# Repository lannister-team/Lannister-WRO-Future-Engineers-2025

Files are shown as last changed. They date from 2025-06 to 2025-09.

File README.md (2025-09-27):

<h1 align="center"><strong>Lannister Team</strong></h1>

<p align="center"><strong>WRO 2025 Local Final: Future Engineers</strong></p>

<p align="center">
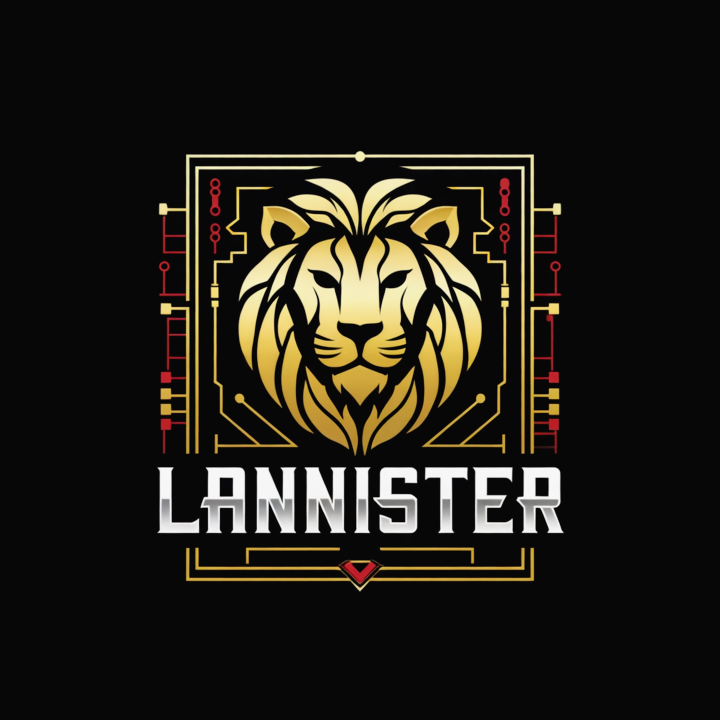
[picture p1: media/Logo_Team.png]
Lannister Team Logo
  
</p>

<p align="center">
  This is the official repository of <strong>Team Lannister</strong> for the international final of the <strong>WRO2025</strong> season.
</p>

## Table of Contents

- [Engineering Materials Repository](#engineering-materials-repository)
  - [Folder Structure](#-folder-structure)
    - [t-photos](#t-photos)
    - [v-photos](#v-photos)
    - [video](#video)
    - [schemes](#schemes)
    - [src](#src)
    - [models](#models)
    - [media](#media)
  - [Car Components](#-car-components)
    - [Introduction](#introduction)
    - [Mobility Management Components](#mobility-management-components)
    - [Motor Integration and Drive System](#-motor-integration-and-drive-system)
      - [Drive System Overview](#--drive-system-overview)
    - [Ackermann Steering System](#-ackermann-steering-system)
      - [How it works](#--how-it-works)
    - [System Elements Overview](#-system-elements-overview)
      - [Microcontrollers and Computing Units](#-microcontrollers-and-computing-units)
        - [Arduino Uno](#arduino-uno)
        - [Raspberry Pi 5 (Model B)](#raspberry-pi-5-model-b)
      - [Vision System](#-vision-system)
      - [Motors and Actuation](#-motors-and-actuation)
      - [Motor Driver](#-motor-driver)
      - [Distance and Motion Sensing](#-distance-and-motion-sensing)
      - [Power Supply](#-power-supply)
    - [Coding Environments](#-coding-environments)
      - [Arduino IDE (C++)](#-arduino-ide-c)
      - [Python](#-python)

# Engineering Materials Repository

This repository contains all materials related to our engineering vehicle project for the competition. The content is organized into several folders as described below.

---

##  Folder Structure

### `t-photos`
- Contains **2 team photos**:
  - An **official team photo**.
  - A **funny photo** with all team members.
  ## 👥 Team Photos

Here are some photos of our team.

| Team Photo | Funny Team Photo |
|---|---|
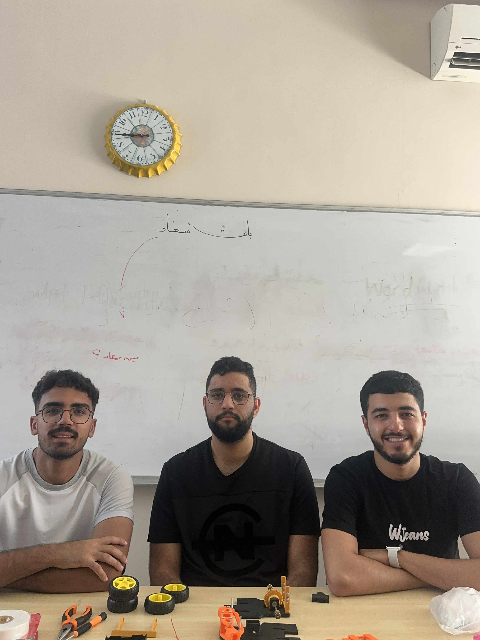
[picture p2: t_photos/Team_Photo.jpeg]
Team Photo
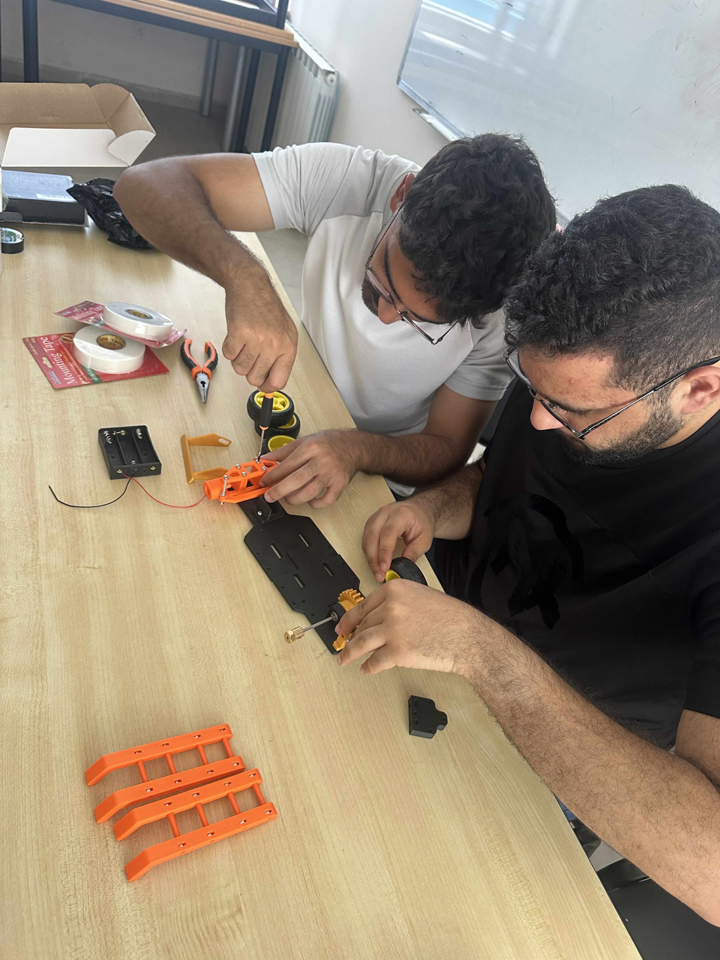
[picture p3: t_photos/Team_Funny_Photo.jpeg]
Funny Team Photo
|  |  |

### `v-photos`
- Contains **6 photos of the vehicle**:
  - Captured from **every side**, as well as from the **top and bottom**.
  ## 📸 Vehicle Photos

Here you can see a selection of the vehicle photos from different angles.  
All images are stored inside the `v_photos/` folder.

| Top view | Front view | Back view |
|---|---|---|
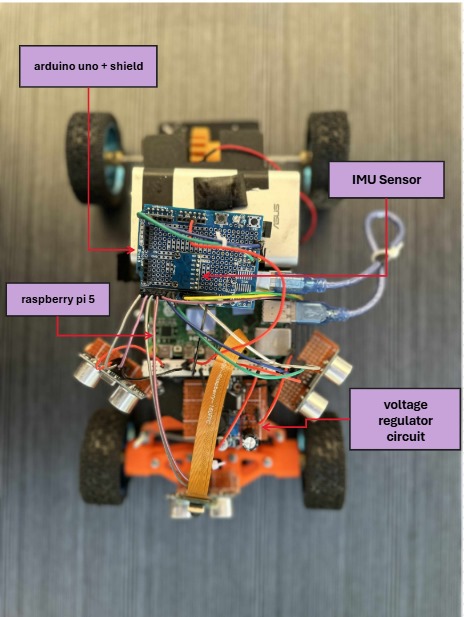
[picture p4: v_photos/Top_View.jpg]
Top view
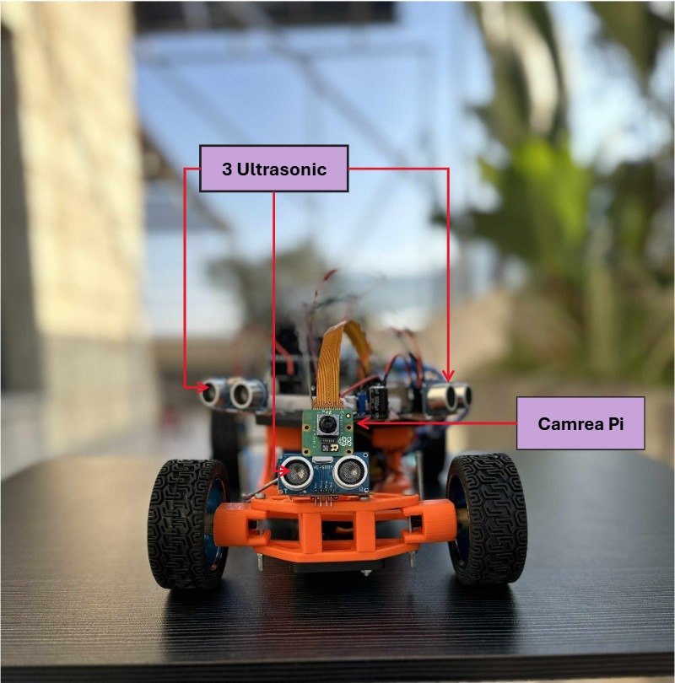
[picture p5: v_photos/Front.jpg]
Front view
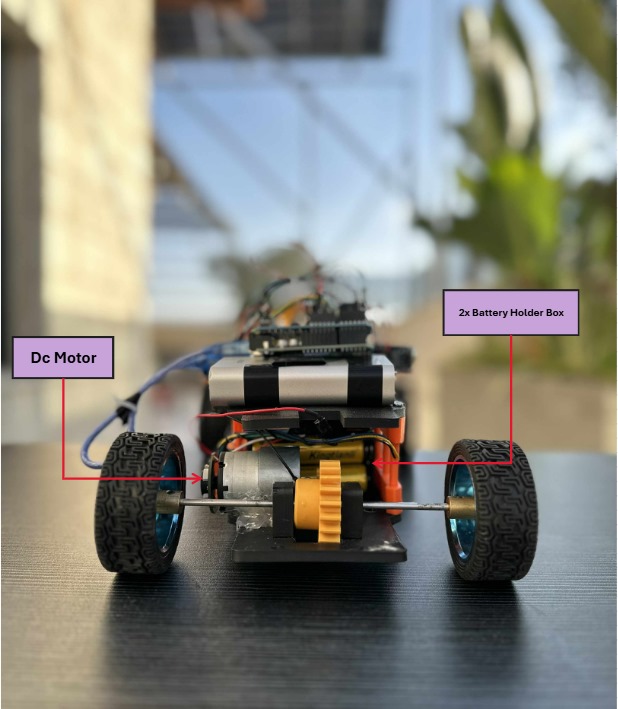
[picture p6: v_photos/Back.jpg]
Back view
|  |  |  |

| Bottom view | Left view | Right view |
|---|---|---|
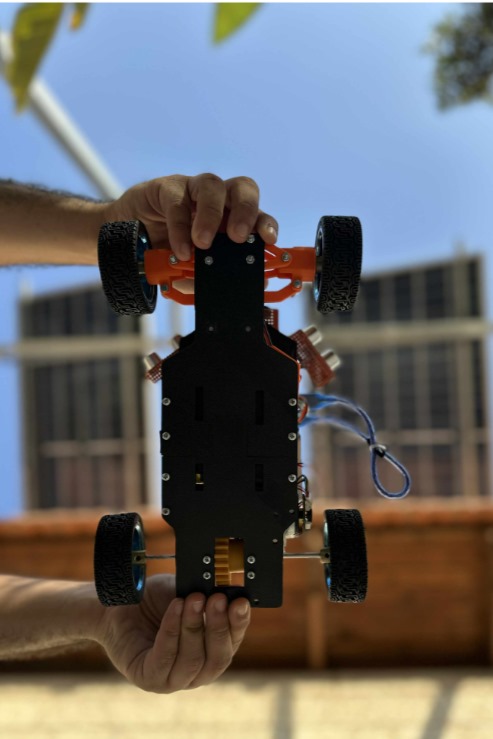
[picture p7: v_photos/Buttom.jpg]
Bottom view
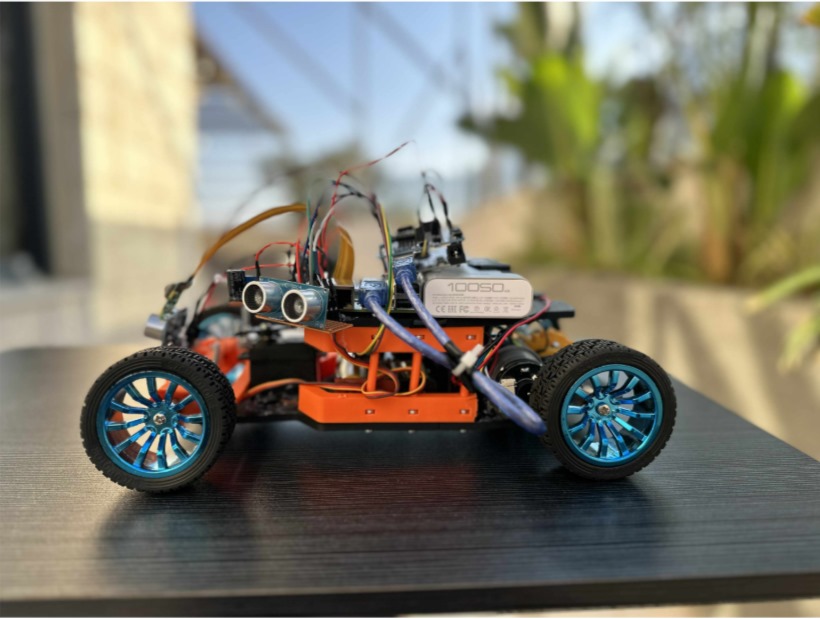
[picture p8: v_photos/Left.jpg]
Left view
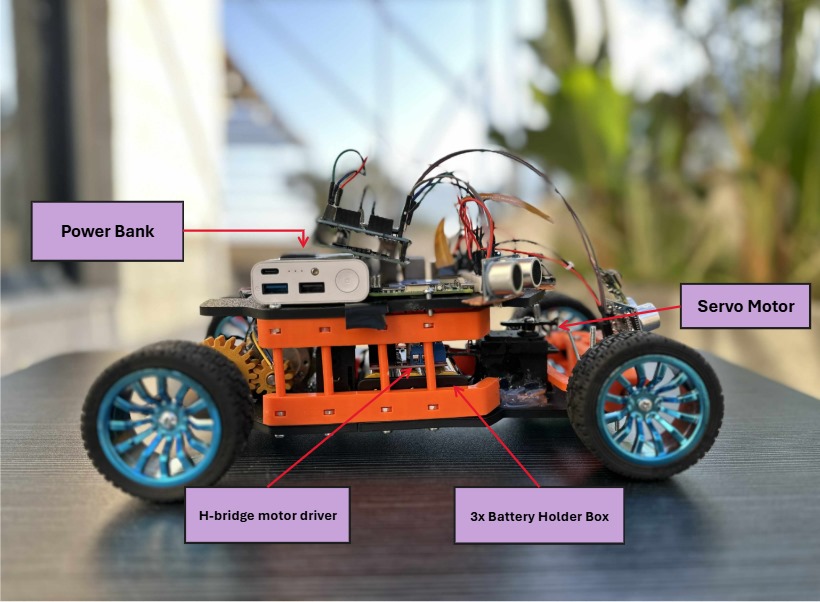
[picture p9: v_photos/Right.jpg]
Right view
|  |  |  |

### `video`
- Contains a `video.md` file with a **link to a demonstration video** showing the vehicle in action.

### `schemes`
- Contains **schematic diagrams** in **JPEG**, **PNG**, or **PDF** format.
- Illustrates all **electromechanical components** used in the vehicle:
  - Electronic components
  - Motors
  - Wiring and connections between them

### `src`
- Contains the **source code** for the control software.
- Includes all components programmed to participate in the competition.

### `models`

- Contains **illustrative diagrams and conceptual models** related to the mechanical design of the robot, including:
  - *Ackermann Steering System in Our WRO 2025 Car*
  - *Differential Gear System in Our WRO 2025 Car*
- These models are used for documentation and explanation purposes only, and do not include 3D-printable or CNC-ready files.
- This folder helps visualize how steering and torque distribution are mechanically implemented in the vehicle.

### `media`
- Contains **images and diagrams** used throughout the documentation, including:
  - Photos of hardware components (motors, sensors, controllers, etc.)
  - System wiring diagrams or mechanical schematics
  - Illustrations for the README and other documentation
- May also include other helpful files such as:
  - Datasets
  - Connection instructions to SBC/SBM
  - Hardware specifications and communication protocols

---

##  Car Components

This structure ensures clear organization and ease of navigation for anyone working on, reviewing, or evaluating the engineering project.

Introduction
Hello, Team Lannister here, let's go a deeper into how this seasons robot is made up !!

### Mobility Management Components

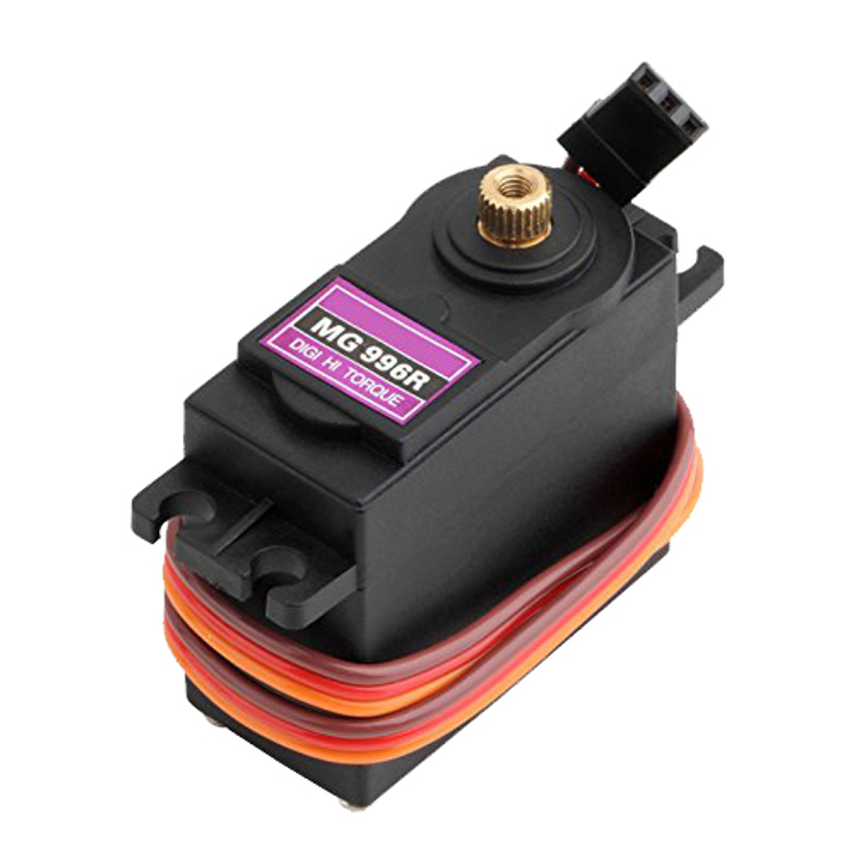
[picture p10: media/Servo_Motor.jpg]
MG996R Servo
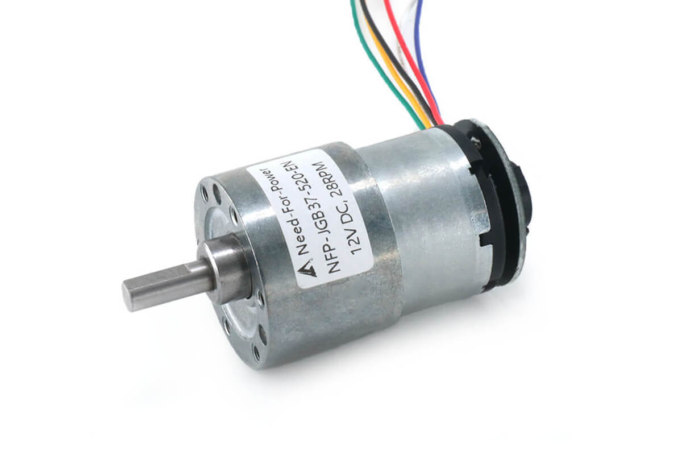
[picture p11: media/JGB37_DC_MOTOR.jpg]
JGB37-520 Encoder Gearmotor
|  |  |
|:---:|:---:|
| **MG996R Servo Motor** <br><br>• Weight: ~55g  <br>• Dimensions: 40.7 × 19.7 × 42.9 mm  <br>• Stall torque: 9.4 kgf·cm at 4.8V <br>• Stall torque: 11 kgf·cm at 6.0V <br>• Speed: 0.20s/60° at 4.8V (no load) <br>• Speed: 0.16s/60° at 6.0V (no load) <br>• Rotational range: 180° <br>• Pulse width: 500–2500 µs | **JGB37-520 Encoder Gearmotor (12V, 530 RPM, 18.8:1)** <br><br>• Rated voltage: 12V <br>• Speed: up to 530 RPM (no load) <br>• Gear ratio: 18.8:1 <br>• Shaft diameter: 6 mm <br>• Motor diameter: 37 mm <br>• Encoder resolution: 11 pulses per revolution <br>• No load current: ~120mA <br>• Stall current: ~2.8A <br>• Stall torque: ~3.2 kgf·cm |

###  Motor Integration and Drive System

To ensure proper implementation of the DC 12V encoder gear motor and the servo motor, both a motor driver and a mechanical differential were selected as essential components of the drive system.

The encoder gear motor is responsible for powering the mechanical differential, which then distributes motion evenly to the rear wheels. This configuration was chosen due to the torque multiplication offered by the differential — a key factor for achieving precise maneuverability within constrained environments, such as a competition playing field.

The integrated gear reduction system in the motor provides several advantages:

- Simplified mechanical design  
- Enhanced power and torque output  
- High durability due to the sealed and enclosed housing  

This combination of components enables smooth, responsive, and reliable mobility suitable for both fine control and sustained movement under varying load conditions.

####  Drive System Overview

<p align="center">
  Mechanical Differential
</p>

---

###  Ackermann Steering System

To achieve realistic turning behavior and reduce tire slip during sharp turns, the robot implements an **Ackermann steering mechanism**. This system is commonly used in cars and robotics for accurate cornering.

####  How it works:

When a vehicle turns, the inner front wheel must rotate at a **sharper angle** than the outer wheel. Ackermann steering geometry ensures this by linking the steering arms to pivot at a calculated angle, allowing the two front wheels to point towards the center of a turning circle.

This offers the following benefits:

- Reduced tire wear during turns  
- Improved energy efficiency  
- More accurate and realistic path-following behavior  
- Ideal for tight indoor environments like robotic competitions

<p align="center">
  Ackermann Steering Diagram
</p>

---

###  System Elements Overview

This section outlines the main hardware components integrated into the robot, including control units, sensors, power elements, and motor drivers.

---

####  Microcontrollers and Computing Units

### Arduino Uno

The Arduino Uno serves as the main microcontroller responsible for low-level control tasks such as motor actuation and sensor data acquisition. It interfaces directly with the motor driver, sensors, and power supply through individual wiring and connections without the use of a custom shield.

Connections are managed via standard Arduino input/output pins, with careful wiring to ensure stable power distribution and reliable communication with all peripheral components.

<p align="center">
  Arduino Uno
</p>

To simplify wiring and improve reliability, we also used an **Arduino Shield**.  
The shield allowed us to:
- Reduce the complexity of manual wiring.  
- Ensure more stable connections between the Arduino and external modules.  
- Provide an easier way to connect sensors, motors, and the power supply without soldering.  

<p align="center">
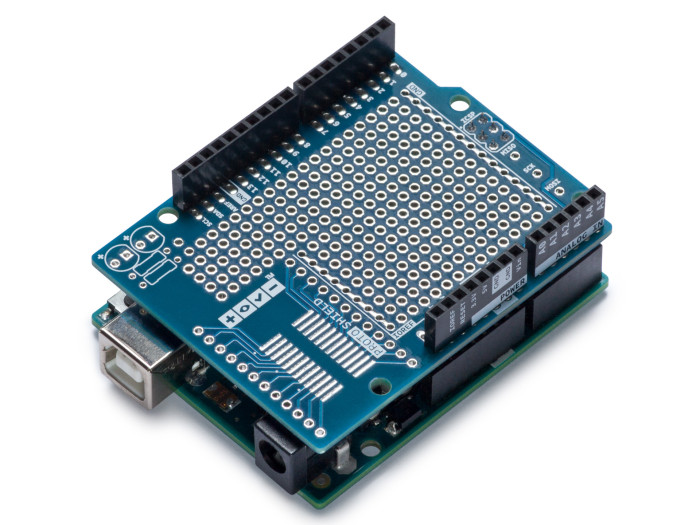
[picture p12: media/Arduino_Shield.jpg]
Arduino Shield
  
</p>

### Raspberry Pi 5 (Model B)

The Raspberry Pi 5 serves as the high-level processing unit, handling tasks such as path planning, camera data processing, and advanced control logic. Model B features a quad-core ARM Cortex-A76 processor running at 2.4GHz, up to 8GB RAM, dual 4K display output, USB 3.0 support, Gigabit Ethernet, built-in Wi-Fi and Bluetooth 5.0.

<p align="center">
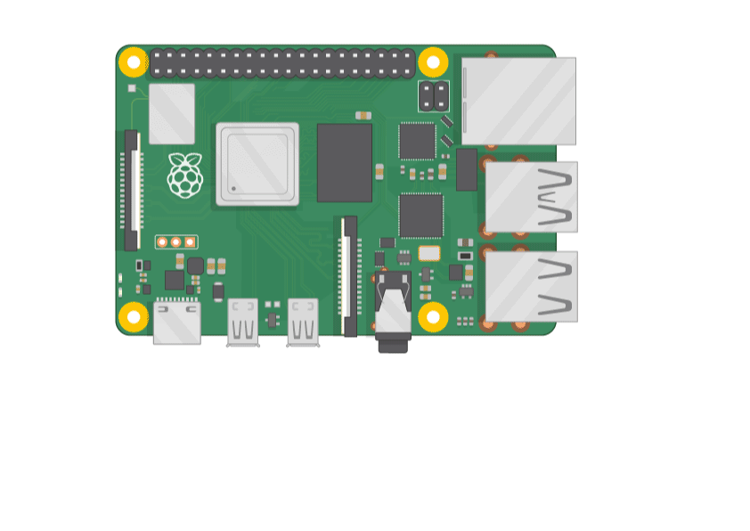
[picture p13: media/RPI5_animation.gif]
Raspberry Pi 5
  
</p>

---

####  Vision System

- **Raspberry Pi Camera Module**  
  The robot is equipped with the official Raspberry Pi Camera Module, providing real-time video input for image-based navigation or line-following tasks. The camera is directly connected to the Pi via the CSI interface for low-latency image capture.

<p align="center">
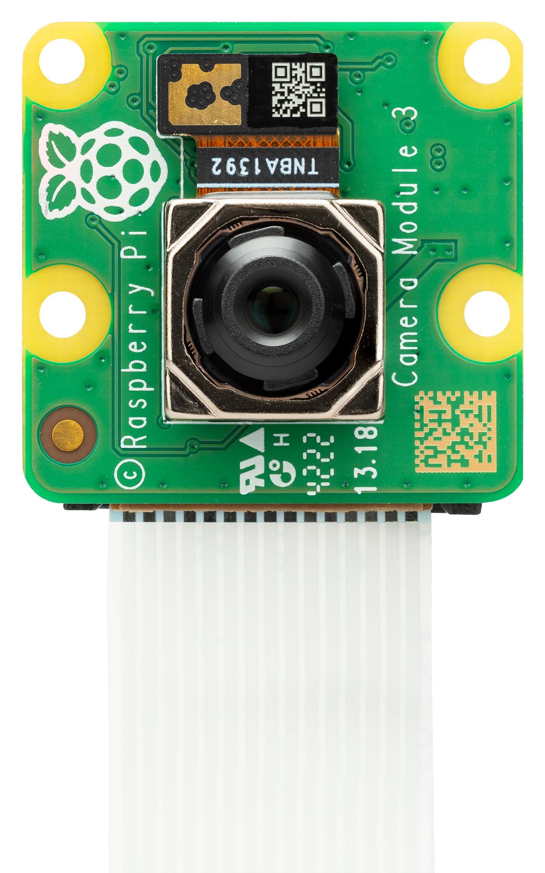
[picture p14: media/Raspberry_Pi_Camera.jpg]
Raspberry Pi Camera Module
  
</p>

---

####  Motors and Actuation

- **Motors Configuration**  
  The robot includes:
  - **1 DC Encoder Gearmotor** for rear-wheel drive (forward and backward motion).
  - **1 SG90 Servomotor** for steering the front wheels (left/right movement).

  These motors work together to allow omnidirectional navigation on a flat surface. Specifications include:
  - Torque: ~35 g·cm
  - Speed range: 0.22 m/s (min) – 0.71 m/s (max)  
  *(Note: 0.22 m/s is the robot's minimum effective speed; the motor itself can operate slower.)*

---

####  Motor Driver

- **L298N Dual H-Bridge Motor Driver**  
  The L298N module is used to control the DC and servo motors. It consists of:
  - An L298 integrated motor driver IC
  - A 78M05 5V regulator
  
  Features:
  - Can control up to 2 DC motors (direction + speed), but two in out car
  - Compatible with TTL logic levels (from Arduino UNO)

<p align="center">
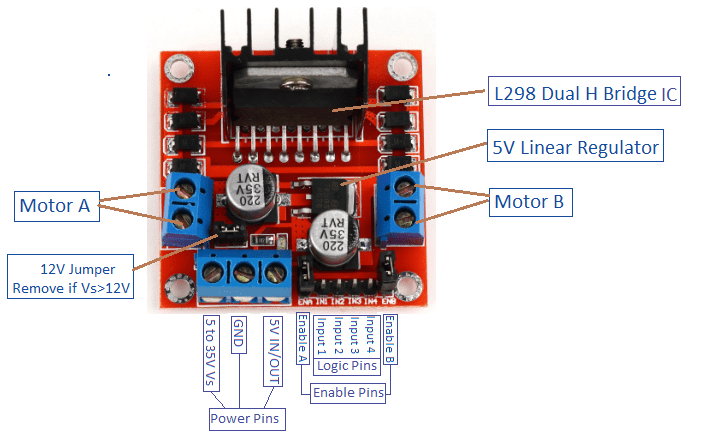
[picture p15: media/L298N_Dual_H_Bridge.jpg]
L298N Motor Driver
  
</p>

---

####  Distance and Motion Sensing

- **HC-SR04 Ultrasonic Sensors**  
  The robot uses **3 ultrasonic sensors** placed at the front, left, and right to detect obstacles and measure distances. Each sensor operates as follows:
  - Emits 8 ultrasonic pulses at 40kHz via the TRIG pin.
  - Detects reflected sound using the ECHO pin.
  - Measures time of flight to calculate distance (2–450 cm range).
  
  These sensors are not affected by sunlight or dark materials, but may struggle with acoustically soft surfaces (e.g., cloth or wool).

<p align="center">
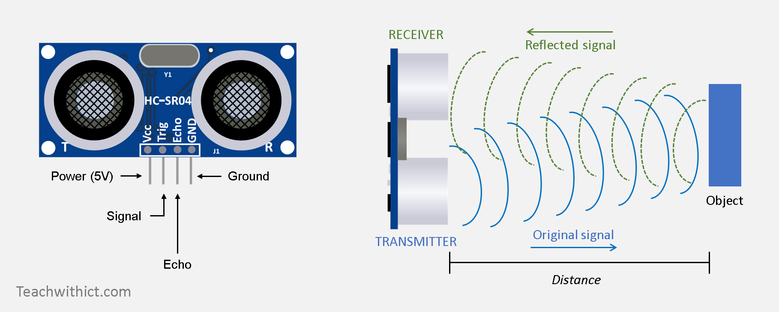
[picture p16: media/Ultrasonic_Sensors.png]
Ultrasonic Sensors
  
</p>

- **IMU Sensor (Inertial Measurement Unit)**  
  The robot includes an IMU sensor (e.g., MPU6050 or similar) that provides motion data through **gyroscope and accelerometer readings**. This allows:
  - Orientation tracking
  - Tilt detection
  - Smoother navigation control (especially in turns or uneven motion)

  The IMU is connected via I2C to the Arduino, which processes raw motion data or forwards it to the Raspberry Pi for sensor fusion and decision making.

<p align="center">
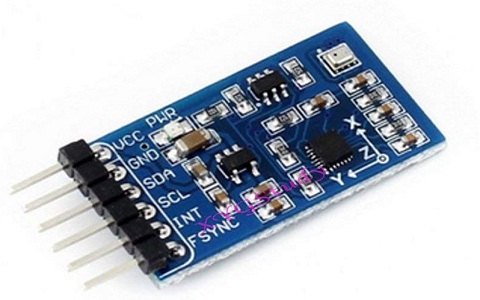
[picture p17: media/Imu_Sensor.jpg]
IMU Sensor
  
</p>

---

####  Power Supply

- **Power bank**
  The power bank will be our main source for keeping the Raspberry PI charged, which will also give the arduino its charge

- **3x - 3.7 Li-Po**  
  The robot is powered using a **3x - 3.7 Li-** Po-- 4.2 Max ~= 12.6v on max , to enable the motor to receive power through the L298N driver module.

###  Coding Environments

The robot's software is developed using two main programming environments: **Arduino IDE (C++)** and **Python**. Each environment is responsible for different layers of control, from low-level motor actuation to high-level vision processing.

---

####  Arduino IDE (C++)

The **Arduino Integrated Development Environment (IDE)** is a cross-platform application (available for Windows, macOS, and Linux) used to program Arduino-compatible boards. Written in Java, the IDE supports both C and C++ languages with simplified structure requirements.

Key features:
- Provides built-in libraries for common I/O operations (based on the Wiring framework).
- Requires only two user-defined functions: `setup()` for initialization and `loop()` for continuous execution.
- Uses the GNU toolchain to compile code, and **AVRDUDE** to upload the hex-encoded binary to the board.

**Role in the project:**
- The Arduino IDE is used to program the **Arduino Uno**, which directly controls:
  - Rear-wheel drive motion
  - Steering through the servo motor
- These actions are performed based on movement commands received from the Raspberry Pi Camera (e.g., left/right turns or forward/backward motion).

---

####  Python

**Python** is a high-level, interpreted programming language known for its readability and flexibility.

**Role in the project:**
- Python runs on the **Raspberry Pi 5** and is responsible for:
  - **Camera input handling**
  - **Color and object detection**
  - **Sending motion commands** to the Arduino Uno based on visual analysis

**Libraries**
- OpenCV library will be used to detecet colors (RED, GREEN).

##  Wiring Diagram

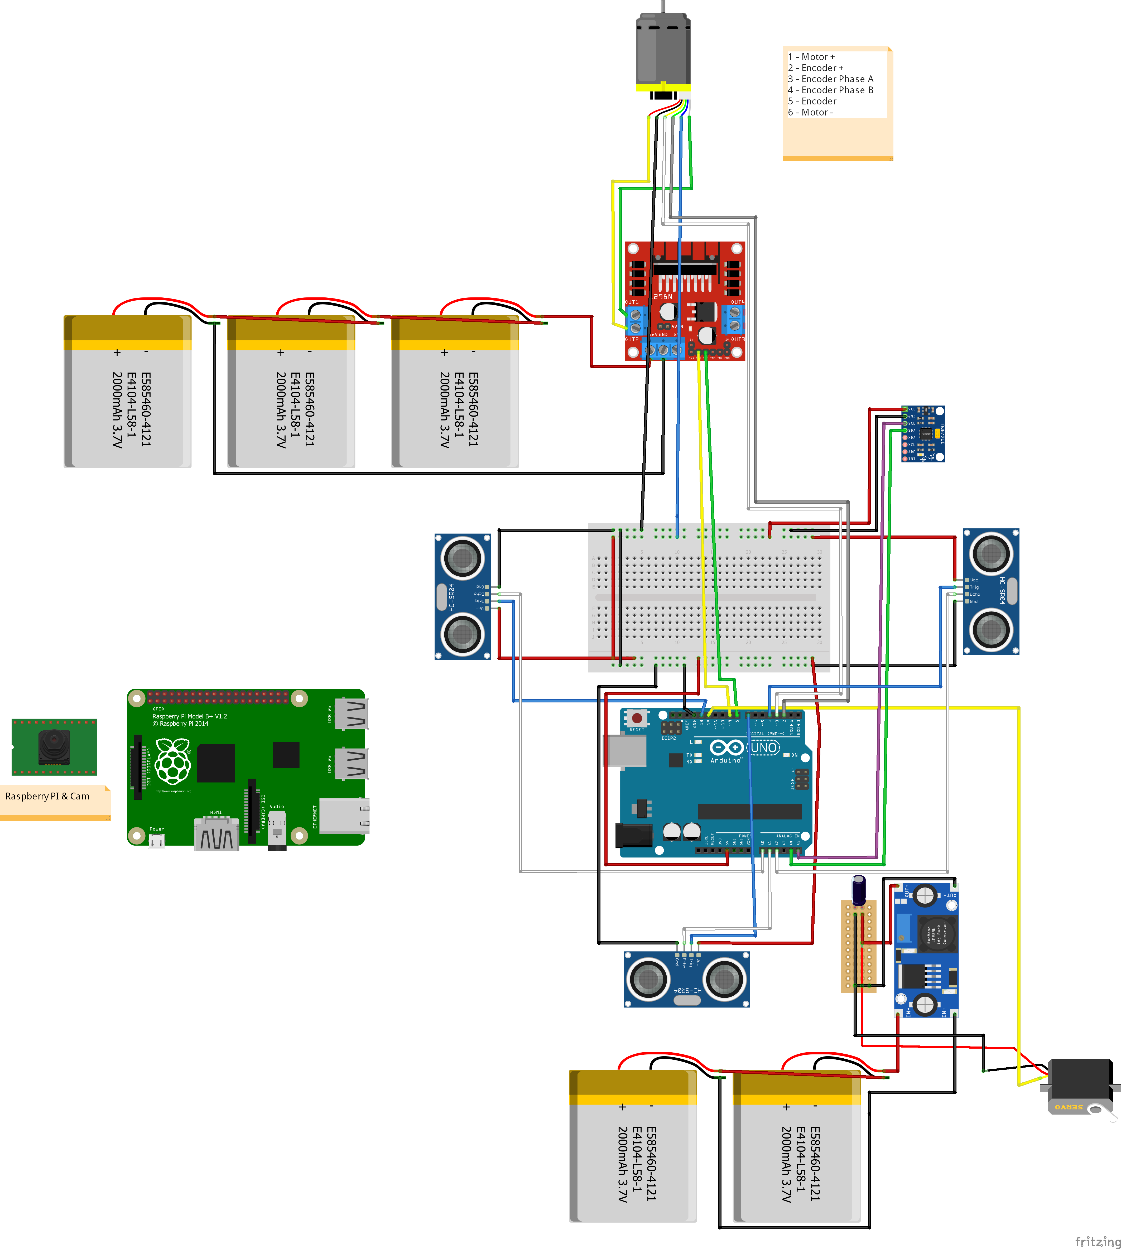
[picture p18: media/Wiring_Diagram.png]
Wiring Diagram


### Explanation

#### 1. Power Distribution
- **Motor Power (12V rail):**  
  Three Li-ion cells (3.7 V each) in series (~11.1 V) power the **L298N H-Bridge**.  
- **Logic Power (5V rail):**  
  Another pack (2 × 3.7 V = ~7.4 V) regulated to **6V** powers the **Arduino Uno**, sensors, and servo.  
- **All grounds are common** across Arduino, motor driver, sensors, and Raspberry Pi.

#### 2. Motor & Driver (L298N H-Bridge)
- **DC Gear Motor with Encoder** connected to OUT1/OUT2 of L298N.  
- Encoder outputs → Arduino digital pins.  
- IN1/IN2 → Arduino (motor direction).  
- ENA → Arduino PWM (speed control).  
- Powered from 3-cell battery pack.

#### 3. Sensors
- **Ultrasonic Sensors (x3 HC-SR04):**  
  Each wired with VCC, GND, Trig, Echo → Arduino pins (front, left, right).  
- **MPU6050 IMU:**  
  I²C (SDA → A4, SCL → A5), VCC (5V), GND.  
- **Raspberry Pi Camera:**  
  Connected to Raspberry Pi 5 CSI port.

#### 4. Actuators
- **Steering Servo Motor:**  
  Powered from regulated 6V, control pin → Arduino PWM.  
- **Relay Module:**  
  Controlled by Arduino digital pin for auxiliary switching.

#### 5. Controllers
- **Arduino Uno:** Low-level control for motor, sensors, and actuators.  
- **Raspberry Pi 5:** Vision processing with Pi Camera → sends movement commands via USB serial.

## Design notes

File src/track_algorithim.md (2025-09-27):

# Track Algorithim
this section for explaining the algorithim used in the Arduino files to win the track
##  Navigation Algorithm

The car’s navigation system combines data from the **IMU**, **Ultrasonic Sensors**, and the **Camera** to make real-time driving decisions.  

---

### 1. Forward Motion (IMU Correction)
- The car drives forward by default.  
- The **IMU (MPU6050)** continuously monitors orientation (yaw/pitch).  
- If the car drifts left or right:  
  - The system calculates the deviation.  
  - The **steering servo motor** adjusts the wheel angle to realign the car.  

---

### 2. Camera-Based Obstacle Detection
- The **Raspberry Pi Camera** identifies the color of the obstacle ahead:  
  - **Red →** The car avoids the obstacle by turning **right**.  
  - **Green →** The car overtakes by moving to the **left**.  

---

### 3. Ultrasonic Safety Check
- Three **ultrasonic sensors** are used: **front, left, and right**.  
- When the camera detects an obstacle:  
  - The system checks the corresponding ultrasonic sensor:  
    - **Red →** Check the **right sensor**.  
    - **Green →** Check the **left sensor**.  
  - If the chosen side is clear (distance above threshold), the car proceeds with the maneuver.  
  - If blocked, the car will **stop** to prevent collision.  

---

### 4. Realignment After Maneuver
- After completing a turn (right or left):  
  - The **IMU feedback** is used again to stabilize the direction.  
  - The **servo motor** returns the wheels to the corrected forward position.  

---

###  Summary of Logic
1. Drive forward and keep straight using the **IMU**.  
2. If the camera detects an obstacle:  
   - **Red → Turn Right** (if right side is clear).  
   - **Green → Overtake Left** (if left side is clear).  
3. Use **ultrasonic sensors** to ensure the chosen side is free.  
4. If blocked, **stop**.  
5. After turning, use **IMU correction** to continue straight.  

---

This algorithm ensures:  
- **Stability** through IMU correction.  
- **Safety** with ultrasonic distance checks.  
- **Smart decision-making** using camera color detection.

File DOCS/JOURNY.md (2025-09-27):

a jounry that shows our development process , choices , failures , improvements

##  Development Journey

Our development process was not a straight path—it was a journey full of challenges, failures, learning, and improvements. Below is an overview of the key stages we went through:

---

###  Step 1: First Steps with 3D Printing
- At the beginning, we struggled to learn how to design and work with **3D-printed parts**.  
- We tried creating our own designs, but the results were not practical.  
- Fortunately, we found an existing design online that fit our needs.  
- We made **major improvements and modifications** to adapt it to our project.  
- After printing the chassis, the result was promising, but a problem appeared:  
  - The **DC motor was longer than the chassis base**, causing fitting issues.  
- After several trials and adjustments, we solved this issue successfully.  

---

###  Step 2: Motor Limitations and Upgrades
- The original **DC motor was too weak** and could not deliver enough power.  
- We replaced it with a **stronger and more efficient motor**.  
- This upgrade was not straightforward—we faced difficulties with mounting and alignment.  
- With persistence, we managed to fix and stabilize the new motor in place.  

---

###  Step 3: Servo Motor Challenges
- The first **servo motor** we used had **low torque**, which was not enough for proper steering.  
- We upgraded to a **high-torque servo motor**.  
- The new servo required **6V power**, but our system could not supply this directly.  
- To solve this:  
  - We combined **two 3.7V Li-ion batteries** in series to get **7.4V**.  
  - We used a **voltage regulator** to clean and stabilize the output at **6V**.  
- This solution powered the high-torque servo safely and reliably.  

---

###  Conclusion
Every stage of our journey was a cycle of **trial and error**.  
Each challenge pushed us to learn and improve:  
- From mastering 3D printing,  
- To upgrading motors,  
- To solving power delivery issues.  

These experiences shaped our project into a **stronger, more reliable system**.

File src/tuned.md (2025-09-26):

How we tuned our sensors
Tuning & Calibration (Ultrasonic • IMU • Servo)

This vehicle didn’t work “out of the box.” We spent a lot of time tuning three pieces that control stability and decisions: the **steering servo**, the **ultrasonic sensors**, and the **IMU**. Below is how we approached each one and what we learned.

---

### 1) Steering Servo — center, left, right

**Goal**
- Find the exact **center angle** for straight driving, and the **left/right angles** for safe, consistent turns without over-steer.

**What we did**
- Locked the car on a flat surface and **swept the servo** in small steps to see when wheels actually point straight.
- Set an initial **CENTER** angle, then measured turning radius to define **LEFT_MAX** and **RIGHT_MAX** that do not hit mechanical limits.
- Added a small **dead-band** so tiny IMU noise doesn’t cause jitter.
- Limited the **rate of change** (deg/s) so turns are smooth.

**Problems we hit**
- The horn alignment and gear **backlash** made “90° = straight” false.  
- Jitter from power noise → solved by giving the servo **separate 6 V rail with regulator** and common GND.
- Over-steer at high speed → fixed with **rate limiting** and smaller target angles.

**Final parameters (example)**
- `CENTER_ANGLE = 65°`  
- `LEFT_MAX = 0°`, `RIGHT_MAX = 90°`  
- `DEAD_BAND = ±1°`  
- `MAX_STEER_RATE = 180°/s`  
these are a starting point we reached after many trials.

### 2) Ultrasonic Sensors — distances & turn trigger

**Goal**
- Reliable distance reading to decide **when to trigger a turn** and **which side** is safer.

**What we did**
- Calibrated each sensor against known distances (20, 30, 40, 60 cm).
- Used **median/average of N samples** to fight noise.  
- Staggered triggers (few ms apart) to reduce **cross-talk** between sensors.
- Defined thresholds:
  - **Front stop/turn trigger** (when to stop trying to go straight).
  - **Side clearance** (minimum safe space to pick a side).
  - **Side margin** (how much one side must beat the other).

**Problems we hit**
- Cross-talk gave random spikes → **inter-sensor delays** helped.  
- Narrow FOV misalignment → we re-angled the brackets slightly outward.  
- Glossy surfaces returning bad echoes → we average more samples near shiny objects.

**Decision rule (no camera)**
- If `front < FRONT_TURN_TRIG_CM`:  
  - Compare `left` vs `right`.  
  - Choose the side with **greater distance** by at least `SIDE_MARGIN_CM`.  
  - If tie, we **prefer right** (configurable).  
  - If neither side ≥ `SIDE_CLEAR_CM` → **STOP**.

---

### 3) IMU (MPU6050) — keep it straight

**Goal**
- Use the IMU to **hold a straight heading** and gently correct drift without oscillations.

**What we did**
- Performed **gyro/accel offset calibration** at startup (vehicle still).  
- Fused gyro+accel with a **complementary/low-pass filter** to reduce noise.  
- Defined **target heading** at the moment we start moving straight.  
- Applied **PID control** on the heading error to generate small steering corrections.
- Added **integral wind-up guard** and **output clamp** to avoid over-correction.

**Problems we hit**
- Drift over time → improved with better calibration and a gentle filter (not too slow).  
- Vibration coupling into the IMU → we **soft-mounted** the board and reduced motor PWM ripple.  
- Noise causing servo twitch → the **dead-band** and PID tuning fixed it.

**Control loop idea**
- Error = `target_heading − current_heading`  
- Servo correction = `PID(error)`  
- Apply correction only if `|error| > DEAD_BAND`

---

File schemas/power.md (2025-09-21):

# Power

## Power Summary Table

A table for all components power summary

| Component | Powered By | Voltage |
|---|---|---|
| Raspberry Pi 5 | Powerbank | 5V (USB-C) |
| Raspberry Pi Camera | Raspberry Pi 5 | 3.3V / Internal|
| Arduino Uno | Raspberry Pi 5 | 5V (via USB) |
| Ultrasonic Sensors (x3) | Arduino Uno | 5V |
| L298N H-Bridge | External Battery | 3x (3.7 Li-Ion)|
| DC Motor | L298N H-Bridge | 3x (3.7 Li-Ion)|
| DC Motor Encoder | Arduino Uno | 5V |
| MPU6050 IMU | Arduino Uno | 5V (I2C) |
| Voltage Regulator | External Battery | 2x (3.7 Li-Ion)|
| Servo Motor | Voltage Regulator & Capacitor | 6V  |

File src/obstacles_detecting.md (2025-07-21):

##  Obstacles Detecting

The obstacle detection system is implemented using **Python**, running on a **Raspberry Pi** with a **Pi Camera v3**. The main goal is to identify **red** and **green** obstacles placed on the track and send their status to the Arduino for real-time driving decisions.

###  Code Purpose

The `camera.py` script continuously captures frames, detects the presence of red or green colored shapes using **OpenCV**, and sends a single-character signal (`'R'`, `'G'`, or `'N'`) over **serial communication** to the Arduino.

---

###  Libraries Used

| Library | Role |
|---|---|
| `OpenCV (cv2)` | For image processing and color detection |
| `picamera2` | For accessing and configuring the Raspberry Pi camera |
| `numpy` | Efficient handling of image arrays |
| `serial` | Sending obstacle detection signals to Arduino via USB |
| `time` | Introduce delays and warm-up periods |

---

###  How It Works

#### 1. **Camera Setup**
- The camera is initialized using `picamera2` and configured to capture video at **640x480 resolution** in BGR format.
- A short `sleep(1)` delay is used to let the camera stabilize before processing starts.

#### 2. **Frame Processing**
Each captured frame goes through the following steps:

1. **Color Conversion**
   - Frame is converted from BGR to **HSV** color space.
   - HSV is preferred for color detection because it separates intensity (brightness) from color (hue), making it more robust under different lighting.

2. **Color Masking**
   - Two HSV ranges for red are used (`[0-10]` and `[160-179]`) because red wraps around the HSV hue circle.
   - One range for green (`[40–85]`) is sufficient.
   - `cv2.inRange()` is used to create binary masks (white for detected color, black for everything else).

3. **Morphological Filtering**
   - A **5×5 kernel** is used with `cv2.morphologyEx()` to eliminate noise (remove small dots or gaps in the mask).

4. **Contour Detection**
   - Contours are extracted from each mask using `cv2.findContours()`.
   - For each contour:
     - **Area filtering** ignores shapes with an area less than **2000 px** (to skip small/noisy objects).
     - **Shape approximation** checks that the object is blob-like or squarish (using aspect ratio filter `0.6 < AR < 1.4`).

5. **Color Decision**
   - If a red shape is detected → send `'R'`
   - If a green shape is detected → send `'G'`
   - If no valid shape is detected → send `'N'`

6. **Debouncing Signals**
   - Flags like `green_flag`, `red_flag`, and `none_flag` prevent resending the same character repeatedly unless a new object is detected.

7. **Visualization (Optional)**
   - Camera frame, red mask, and green mask are displayed in real time for debugging using OpenCV's `imshow`.

---

### Why These Hyperparameters?

| Parameter | Value | Why Chosen |
|---|---|---|
| Frame size | `640x480` | Standard resolution: good balance of performance and accuracy |
| Red HSV range | `[0-10] & [160-179]` | Red wraps around hue circle in HSV |
| Green HSV range | `[40–85]` | Matches typical green object shades in WRO challenges |
| Area threshold | `2000 px` | Filters out tiny shapes and noise |
| Morph kernel size | `5×5` | Enough to clean up small noise without destroying object shape |
| Aspect Ratio (AR) Range | `0.6 – 1.4` | Detects rectangles or blobs, avoids lines or skewed shapes |
| Serial Baud Rate | `9600` | Matches Arduino’s UART speed for stable communication |

---

###  Output to Arduino

| Color Detected | Signal Sent |
|---|---|
| Green | `'G'` |
| Red | `'R'` |
| None | `'N'` |

Arduino reads this serial data using `Serial.readStringUntil('\n')` and processes it to decide how the car should move.

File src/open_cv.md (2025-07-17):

# Open_CV

## What is OpenCV?

**OpenCV (Open Source Computer Vision Library)** is a powerful, open-source library designed to help machines **see and understand the world visually**. It provides a wide range of tools and functions for:

- Image and video processing  
- Object and color detection  
- Shape recognition  

OpenCV is written in C++, but it has **excellent Python support**, making it beginner-friendly and fast for robotics prototyping.

---

## Why We Integrated OpenCV in Our WRO Car

In the **WRO** challenge, our self-driving car needed to:

- Detect **red** and **green** obstacles on the track  
- React to its surroundings based on visual input  

OpenCV made this possible by allowing us to:

1.  Capture live video from the Raspberry Pi Camera
2.  Detect specific colors 
3.  Detect real shapes  

---

## Why We Don't Use Other Methods for Color-Based Obstacle Detection

One common approach to detecting obstacles and their colors is to use **dedicated color sensors** or **basic proximity sensors combined with color filters**. These sensors can detect specific colors by measuring reflected light intensity at certain wavelengths. While they are relatively simple and inexpensive, they have significant limitations for a complex environment like the WRO track.

For example, color sensors usually:
- Detect only one point or small area, not a full image  
- Cannot distinguish shapes or multiple objects at once  
- Are sensitive to ambient lighting and require careful calibration  
- Have limited range and field of view  

Because our task requires detecting **multiple colored obstacles**, differentiating their shapes and positions on the track in real-time, this method was less suitable.

---

### Comparison Between Color Sensors and OpenCV

| Feature | Dedicated Color Sensors | OpenCV Camera Vision |
|---|---|---|
| **Color Detection** | Yes, but limited to one point or small area | Full image processing with precise color segmentation |
| **Shape Recognition** | No | Yes, detects shapes and contours |
| **Multiple Object Detection** | Difficult, usually only one object at a time | Yes, can detect multiple obstacles simultaneously |
| **Range and Field of View**| Limited, requires proximity to object | Wide field of view, depends on camera lens |
| **Lighting Sensitivity**  | High, ambient light affects accuracy | Less sensitive due to HSV color space filtering |
| **Complexity & Cost** | Simple and inexpensive | More processing power required, but affordable on Raspberry Pi |
| **Integration with Decision Making** | Limited data (color only) | Rich data (color, shape, position) enabling smarter decisions |

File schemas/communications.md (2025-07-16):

## Communication Summary Table

A table for all communications protocol summary

| Component | Connected To | Communication Type / Protocol |
|---|---|---|
| Raspberry Pi Camera | Raspberry Pi 5 | CSI (Camera Serial Interface) |
| Raspberry Pi 5 | Arduino Uno | UART (Serial) |
| Ultrasonic Sensors (x3) | Arduino Uno | Digital I/O (Trig/Echo) |
| L298N H-Bridge | Arduino Uno | PWM + GPIO |
| DC Motor Encoder | Arduino Uno | Digital GPIO / Interrupt |
| MPU6050 IMU | Arduino Uno | I2C (SDA/SCL) |
| Servo Motor | Arduino Uno | PWM |
| DC Motor | L298N H-Bridge | Direct Power Wires |

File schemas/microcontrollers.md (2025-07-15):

# Arduino and Raspberry PI 5

## What is an SBC?

A **Single-Board Computer (SBC)** is a complete computer built on a single circuit board. It contains a processor, memory, storage interfaces, and often networking capabilities. Unlike microcontrollers, SBCs run full operating systems and can handle complex tasks like image processing, artificial intelligence, and multitasking.

## What is the Raspberry Pi 5?

The **Raspberry Pi 5** is the latest generation of the Raspberry Pi family as of 7/15/2025 (mm/dd/yyyy). It's a powerful, compact, and affordable SBC designed for projects ranging from education to advanced robotics.

### Hardware Specs (Our Raspberry Pi 5 - 8GB):
- Quad-core ARM Cortex-A76 CPU @ 2.4GHz
- 8 GB LPDDR4X RAM
- CSI port for camera
- USB 3.0, USB-C power, GPIO header (40 pins)
- MicroSD storage
- Supports HDMI, Ethernet, and Bluetooth/WiFi

RPI5 Diagram

## Why We Use Raspberry Pi in Our WRO Car

We use the Raspberry Pi 5 as the **main brain** of our WRO 2025 car. Its role includes:
- Capturing video from the Pi Camera using the CSI interface
- Running image processing with OpenCV to detect traffic colors and shapes
- Sending these commands to the Arduino Uno over UART serial communication

The Pi runs a full Linux OS, giving us access to powerful libraries for AI, machine learning, and computer vision. It's ideal for handling non-real-time but complex tasks that require high processing power and memory.

RPI5 Animation

---

## What is a Microcontroller?

A **microcontroller** is a compact integrated circuit that contains a processor core, memory, and I/O peripherals on a single chip. It's designed for real-time control tasks like reading sensors or driving motors.

## What is an Arduino?

**Arduino Uno** is a widely-used microcontroller board based on the ATmega328P. It features 14 digital I/O pins (6 of which can do PWM), 6 analog inputs, and a simple USB interface for programming. It doesn’t run an operating system — instead, it executes code written in Arduino C++ directly from memory, making it fast and predictable.

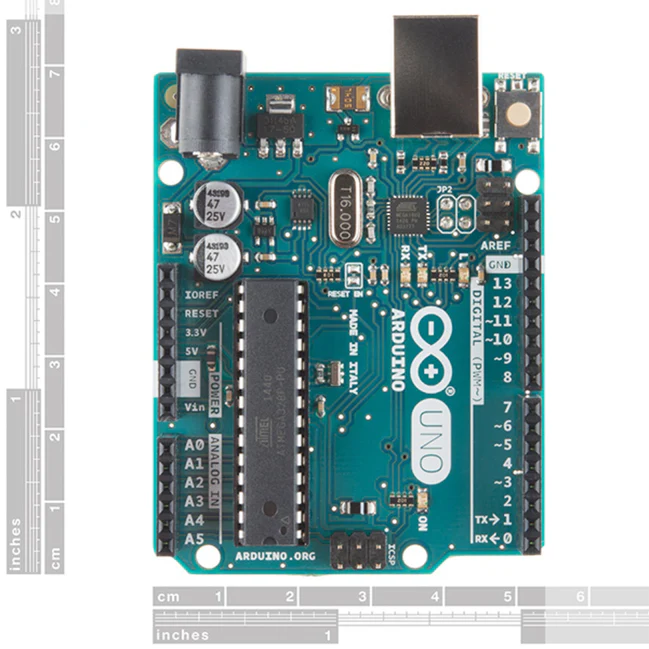
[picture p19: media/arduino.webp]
Arduino Diagram


## Why We Use Arduino in Our WRO Car

The Arduino Uno is used as the **low-level controller** of our car. It handles:
- Reading sensors like ultrasonic distance sensors and the MPU6050 IMU
- Controlling actuators like the DC motor (via L298N H-bridge) and the servo motor for steering
- Receiving high-level commands from the Raspberry Pi and translating them into precise movements

Arduino is reliable, power-efficient, and perfect for real-time applications where fast and consistent pin response is needed.

Arduino Animation

---

## Comparison: Raspberry Pi 5 vs. Arduino Uno

| Feature | Raspberry Pi 5 | Arduino Uno |
|---|---|---|
| Type | Single-Board Computer (SBC) | Microcontroller |
| CPU | Quad-core Cortex-A76 @ 2.4GHz | 8-bit AVR @ 16MHz |
| RAM | 8 GB LPDDR4X | 2 KB SRAM |
| Operating System | Full Linux OS (Raspberry Pi OS) | None (bare-metal code) |
| Programming Language | Python, C++, Java, etc. | Arduino C/C++ |
| Real-time Control | Not deterministic | Very good (deterministic behavior) |
| I/O Pins | 40 GPIO | 14 digital, 6 analog |
| Power Requirement | 5V @ 3A (USB-C) | 5V @ ~50mA via USB |
| Ideal For | AI, image processing, decision logic | Motor control, sensors, real-time I/O|
| Cost | Higher (~$60–$80) | Lower (~$10–$20) |

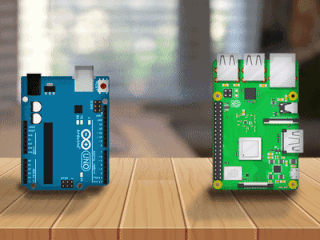
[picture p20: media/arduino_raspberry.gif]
Arduino RPI5


## Summary
At summary, both **Arduino** and **RPI5** is a powerful devices and will help us in the WRO 2025, the will communicate through UART via serial USB

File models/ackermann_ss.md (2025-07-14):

# Ackermann Steering System in Our WRO 2025 Car

## What is Ackermann Steering?

The Ackermann steering geometry is a design principle used to allow the front wheels of a vehicle to follow different turning radii during a turn, this is crucial because the inner wheel must turn more sharply than the outer wheel, so that both wheels point toward a shared center of rotation, this reduces tire slippage and improves control, especially during tight maneuvers.

Ackermann Steering Diagram

## Why We Use It in Our Car

In our WRO 2025 self-driving car, we implemented an Ackermann style steering system to closely mimic the behavior of real vehicles, This makes the car:
- More realistic
- Better at handling curves and corners
- Smoother during autonomous path following

Our system is actuated by a single servo motor, mounted at the bottom of the chassis. The servo is connected to a mechanical linkage that distributes the turning angles to the two front wheels, based on the Ackermann principle.

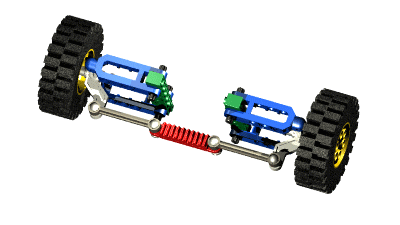
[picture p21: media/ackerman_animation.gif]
Ackermann Linkage Animation


## Geometry and Math Behind It

The concept is based on aligning all wheels toward a common turning point. The steering angles of the inner and outer front wheels can be calculated as:

```
tan(θ_in)  = L / (R - W/2)  
tan(θ_out) = L / (R + W/2)
```

Where:
- `θ_in` is the angle of the inner wheel
- `θ_out` is the angle of the outer wheel
- `L` is the wheelbase (distance between front and rear axles)
- `W` is the track width (distance between left and right front wheels)
- `R` is the turning radius from the center of the car to the turning center

This setup ensures that both front wheels are aligned with their respective turning circles, reducing friction and improving accuracy.

## Real Application in Our Design

In our 3D printed chassis:
- The **servo motor** is mounted at the bottom and connected to a **steering linkage**
- The **linkage arms** are carefully angled to match the required difference between the left and right wheel steering angles
- We tested this system to ensure both smooth turning and reliable mechanical response at low speeds

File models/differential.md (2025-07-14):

# Differential Gear System in Our WRO 2025 Car

## What is a Differential?

A differential is a smart mechanical component that allows two wheels to rotate at different speeds while still receiving power from the same motor, This becomes really important when the car turns, because the outer wheel has to travel a longer path and therefore needs to spin faster than the inner one. Without a differential, both wheels would be locked to the same speed, which causes dragging, skidding, or even poor turning performance.

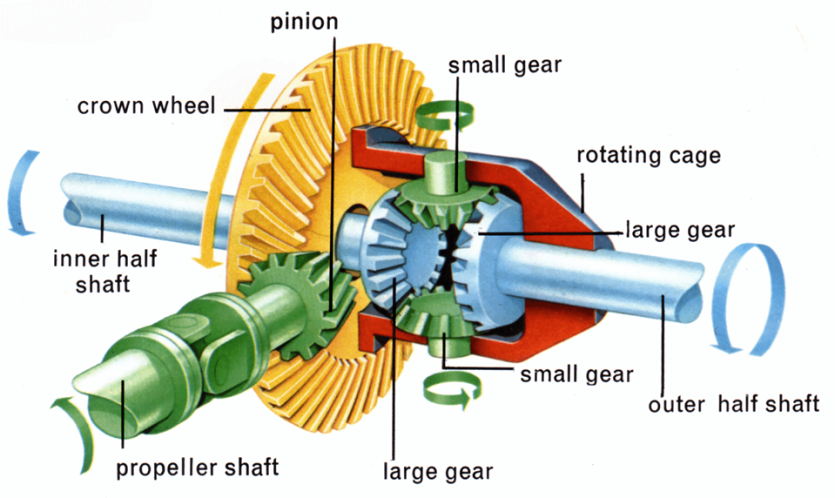
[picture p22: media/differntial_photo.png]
Differential Diagram


## Why We Use It in Our Car

Our WRO 2025 self-driving car uses only one DC motor to drive both rear wheels. This keeps the system simple and efficient, but also means we need a way to let the wheels behave differently when turning. That's where the differential comes in. It lets the inner and outer wheels spin at the speed they need, making turns smooth and controlled, improving grip, and making the whole movement feel more natural and car-like.

## How It Works (Simple Explanation)

Inside a differential, there's a central gear that receives power from the motor, and two side gears that connect to the left and right wheels. A set of small bevel gears inside lets these side gears rotate at different speeds. When driving straight, both wheels spin together. But when turning, the differential adjusts how fast each wheel spins based on the car’s motion, so everything stays balanced and stable without losing traction.

Differential Diagram

## Implementation in Our Design

In our case, we 3D printed a custom differential that sits between the two rear wheels. It’s powered by a 10-tooth gear from the DC motor, which drives a 20-tooth gear on the differential itself. This setup gives us a bit more torque and better control, which helps especially during slow and precise movements required in autonomous driving tasks. It also makes the car behave more like a real vehicle, which is something we aim for in both design and performance.

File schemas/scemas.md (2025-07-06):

# Schemas

## 1. What is This Section For?

This section explains the **hardware wiring** in the WRO 2025 Future Engineers self-driving car project. The car is designed to detect surroundings, make decisions based on visual and distance data, and control its motion accordingly using various electronic modules.

## 2. Main Components

| Component | Function |
|---|---|
| Raspberry Pi 5 | Vision processing and command generation |
| Raspberry Pi Camera | Captures real-time video for color/shape detection |
| Arduino Uno | Handles sensor readings and actuator control |
| L298N H-Bridge | Controls power direction and speed of the DC motor |
| DC Motor with Encoder  | Drives rear wheels and provides feedback on distance/speed |
| 3x Ultrasonic Sensors  | Detects nearby obstacles (front, left, right) |
| MPU6050 IMU | Tracks orientation and Z-axis stability (via gyroscope/accelerometer) |
| Servo Motor | Acts as steering by controlling the angle of the front wheels |
| 9V Battery | External power source for motor driver and motor |
| Breadboard | Distributes power and ground to connected modules |

## 3. Detailed Wiring and Functionality

### Raspberry Pi 5 (8 GB RAM) & Raspberry Pi Camera Module V3

- Purpose: Detect obstacle color and shape.
- Communication: Sends commands (`RED`, `GREEN`, `NONE`) to the Arduino Uno via Serial (UART).
- Why: Arduino may not be that efficient to detect colors.

### Arduino Uno

- Purpose: Central controller for actuators (DC motor, servo) and sensors (ultrasonics, IMU, encoder).
- Communication: Raspberry Pi via Serial (UART) and actuators/sensors through different protocol.

### Three Ultrasonic Sensors 

- Purpose: Detect obstacles to the sides and front for collision avoidance.
- Communication: Trig & Echo.
- Placement: Front, Left, Right.

### DC Motor with Encoder

- Purpose:
  - Drive the car forward or backward.

- Communication: L298N H-Bridge.
- Placement On: Rear wheels.

- Encoder Purpose: Allows us to measure how far the car has moved and regulate speed.
- L298N H-Bridge Purpose:
  - Controls direction and speed using PWM signals.
  - Handles higher current needed for the motor.
- Powered By: 9V battery (external power) to separate motor current from control electronics, preventing brownouts.

### MPU6050 (IMU)

- Purpose: Constantly reports angular movement, especially on the Z-axis (left/right turns).
- Communication: I2C (SCL/SDA - A4/A5) .

### Servo Motor

- Purpose: Acts as steering mechanism for the front wheels.
- Communication: Arduino PWM signal.

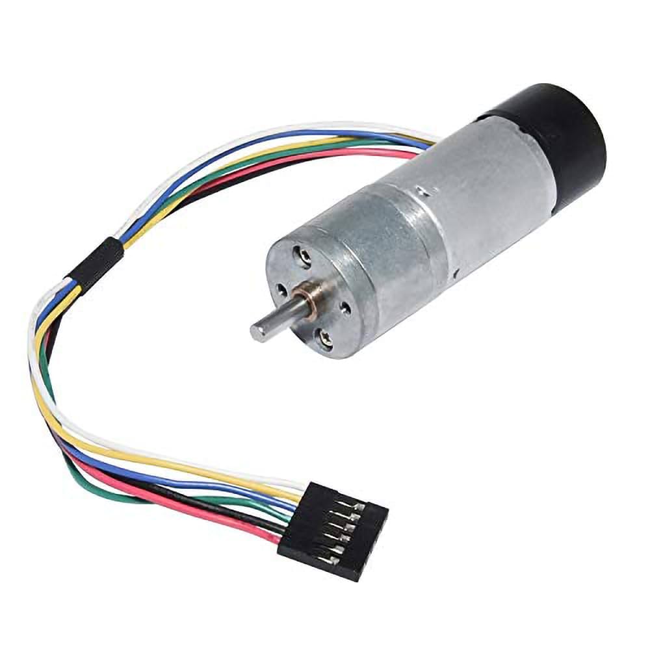
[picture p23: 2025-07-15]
media/Encoder_Gearmotor.jpg

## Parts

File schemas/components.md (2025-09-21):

# Schemas

## What is This Section For?

This section explains the **hardware wiring** and introduces the main **components** in the WRO 2025 Future Engineers self-driving car project. The car is designed to detect surroundings, make decisions based on visual and distance data, and control its motion accordingly using various electronic modules.

## Table of Contents
- [Main Components](#1-main-components) 
- [Components in Detail](#2-components-in-detail)

## 1. Main Components

| Component | Function |
|---|---|
| Raspberry Pi 5 | Vision processing and command generation |
| Raspberry Pi Camera | Captures real-time video for color/shape detection |
| Arduino Uno | Handles sensor readings and actuator control |
| L298N H-Bridge | Controls power direction and speed of the DC motor |
| DC Motor with Encoder  | Drives rear wheels and provides feedback on distance/speed, 300 RPM |
| 3x Ultrasonic Sensors  | Detects nearby obstacles (front, left, right) |
| MPU6050 IMU | Tracks orientation and Z-axis stability (via gyroscope/accelerometer) |
| Servo Motor | Acts as steering by controlling the angle of the front wheels |
| 3x 3.7Li-Ion Battery | External power source for motor driver and motor |
| Voltage Regulator | Decrease the Voltage that enters the servo from the Li-Ion to be appropriate|

## 2. Components in Detail

### Raspberry Pi 5 (8 GB RAM) & Raspberry Pi Camera Module V3

- **Purpose:** Detect obstacle color and shape.
- **Why:** Arduino is not efficient for color detection or running AI code.
- **Communication:** Sends commands (RED, GREEN, NONE) to the Arduino Uno via Serial (UART). 
- **Powered by:** Powerbank

### Arduino Uno

- **Purpose:** Main controller for actuators (DC motor, servo) and sensors (ultrasonics, IMU, encoder).
- **Why:** Sufficient for controlling the sensors in this car; it's cheap and easy to use.
- **Communication:** Receives commands from Raspberry Pi via Serial (UART); controls devices via GPIO.
- **Powered by:** Raspberry Pi 5

### Ultrasonic Sensors (3x)

- **Purpose:** Detect obstacles to the front, left, and right for collision avoidance.
- **Placement:** Front, Left, Right
- **Communication:** Trig & Echo
- **Powered by:** Arduino 5V

### DC Motor with Encoder and L298N H-Bridge

#### DC Motor
- **Purpose:** Drives the car forward or backward.
- **Placement:** Rear wheels
- **Algorithm:** One DC motor is connected to a differential to move both wheels.  
  ➤ Read more: [Differential](../models/differential.md)
- **Communication:** Via L298N H-Bridge
- **Powered by:** L298N H-Bridge

#### Encoder
- **Purpose:** Measures distance and speed to provide feedback for control.
- **Placement:** Inside the DC motor
- **Communication:** Directly to Arduino pins
- **Powered by:** Arduino 5V

#### L298N H-Bridge
- **Purpose:**
  - Controls motor direction and speed
  - Amplifies the current required for the motor
- **Placement:** Centered near the motor
- **Communication:** Controlled by Arduino pins
- **Powered by:** 3x (3.7 Li-Ion) battery

### MPU6050 (IMU)

- **Purpose:** Reports angular motion, especially on the Z-axis (left/right turns).
- **Communication:** I2C protocol
- **Powered by:** Arduino 5V

### Servo Motor

- **Purpose:** Acts as the steering mechanism for the front wheels.
- **Why:** Provides realistic steering behavior (Ackermann steering geometry).
- **Algorithm:** The servo is connected to a linkage that controls the Ackermann steering system.  
  ➤ Read more: [Ackermann Steering System](../models/ackermann_ss.md)
- **Communication:** Controlled by Arduino pins
- **Powered by:** 2x (3.7 Li-Ion) batteries with 6V voltage regulator and a capcitor

---

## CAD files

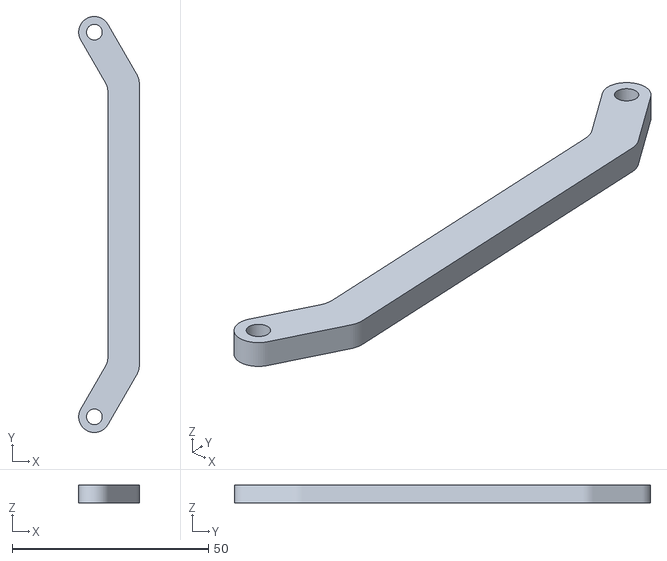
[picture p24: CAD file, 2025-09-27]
models/3D_Models/Steering Arm.stl
15.5 x 106.0 x 4.50

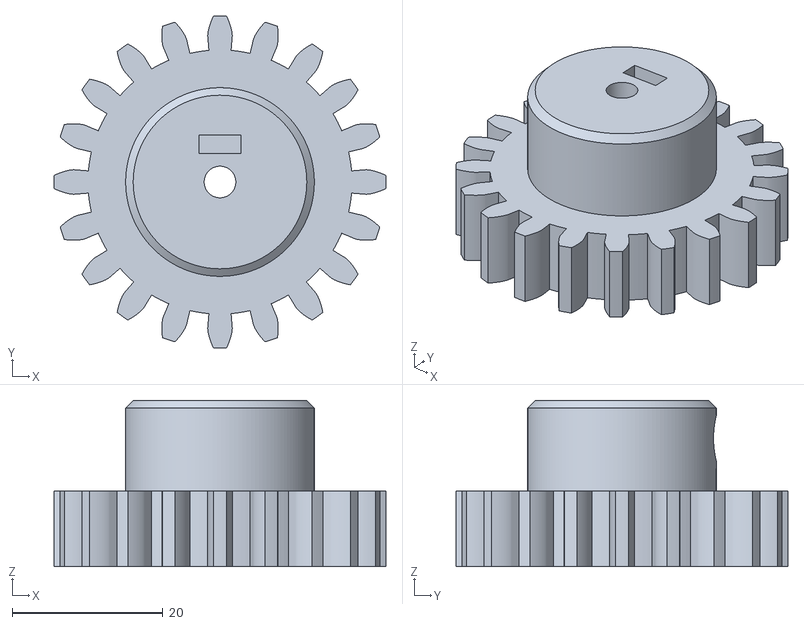
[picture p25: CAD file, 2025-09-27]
models/3D_Models/RC CAR_Gear 20 teeth v2.stl
44.0 x 44.0 x 22.0

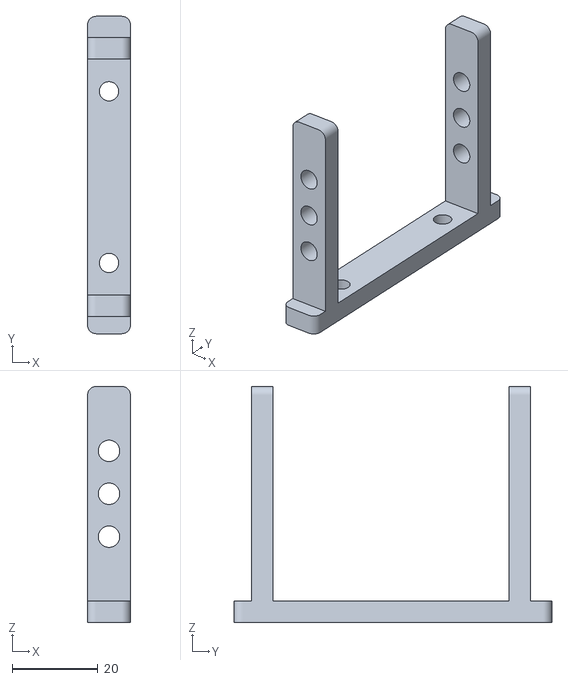
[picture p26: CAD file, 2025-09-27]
models/3D_Models/Rear Wing.stl
10.0 x 74.0 x 55.0

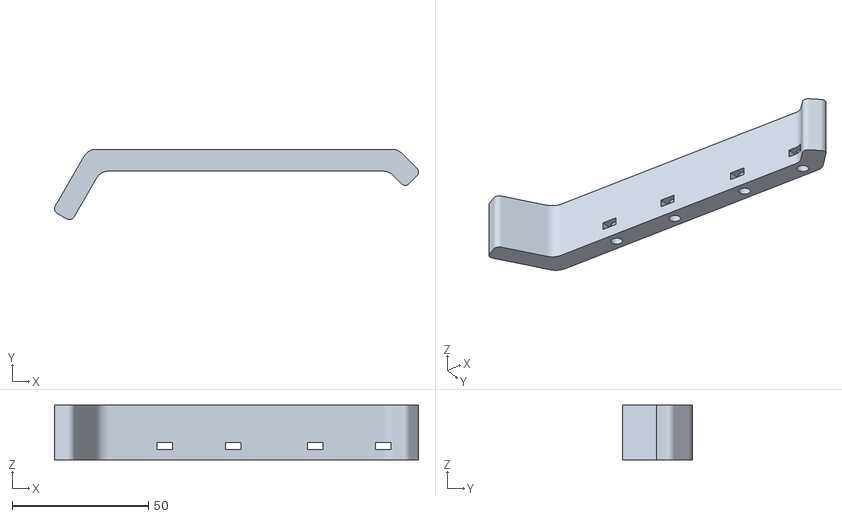
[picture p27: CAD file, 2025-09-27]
models/3D_Models/Cover.stl
133.4 x 25.8 x 20.0

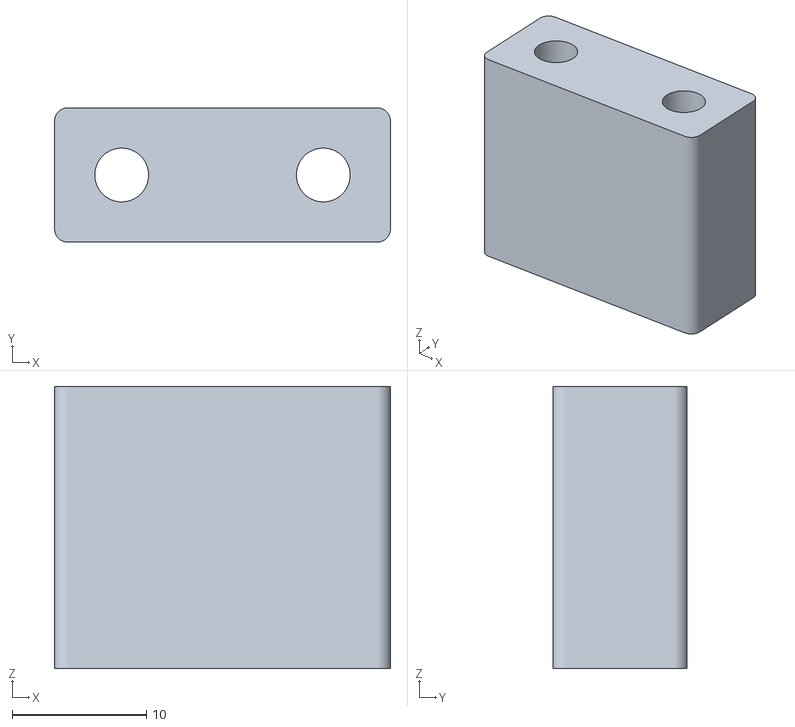
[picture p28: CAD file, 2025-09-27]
models/3D_Models/Arm Support.stl
25.0 x 10.0 x 21.0

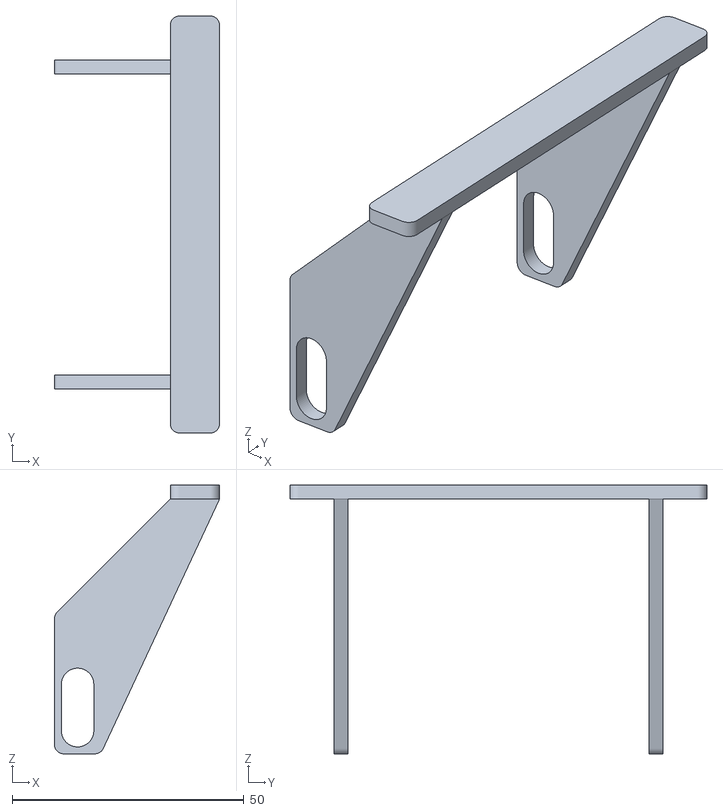
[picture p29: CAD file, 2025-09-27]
models/3D_Models/Wing.stl
35.6 x 90.0 x 58.0

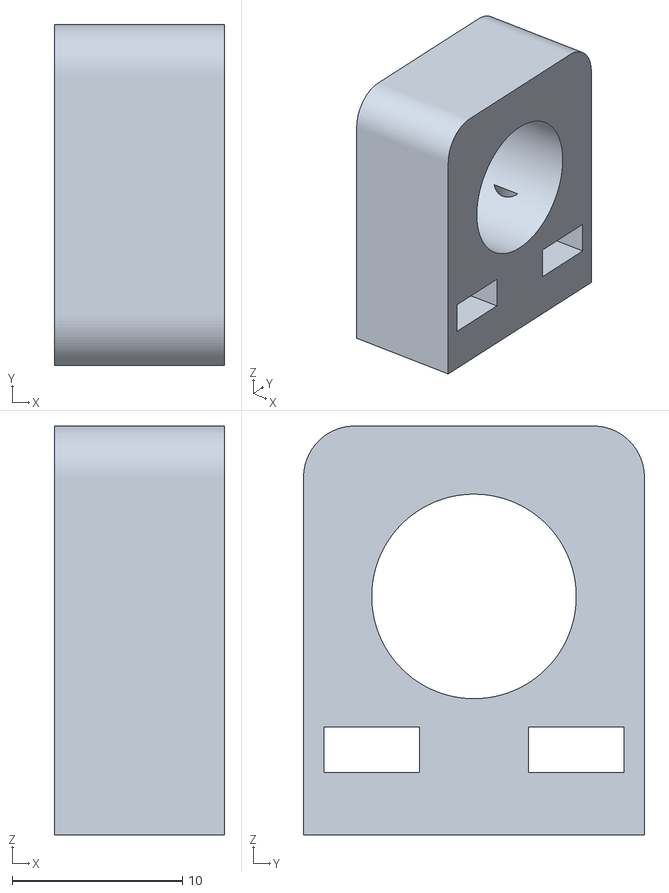
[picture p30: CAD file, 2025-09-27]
models/3D_Models/Shaft Support.stl
10.0 x 20.0 x 24.0

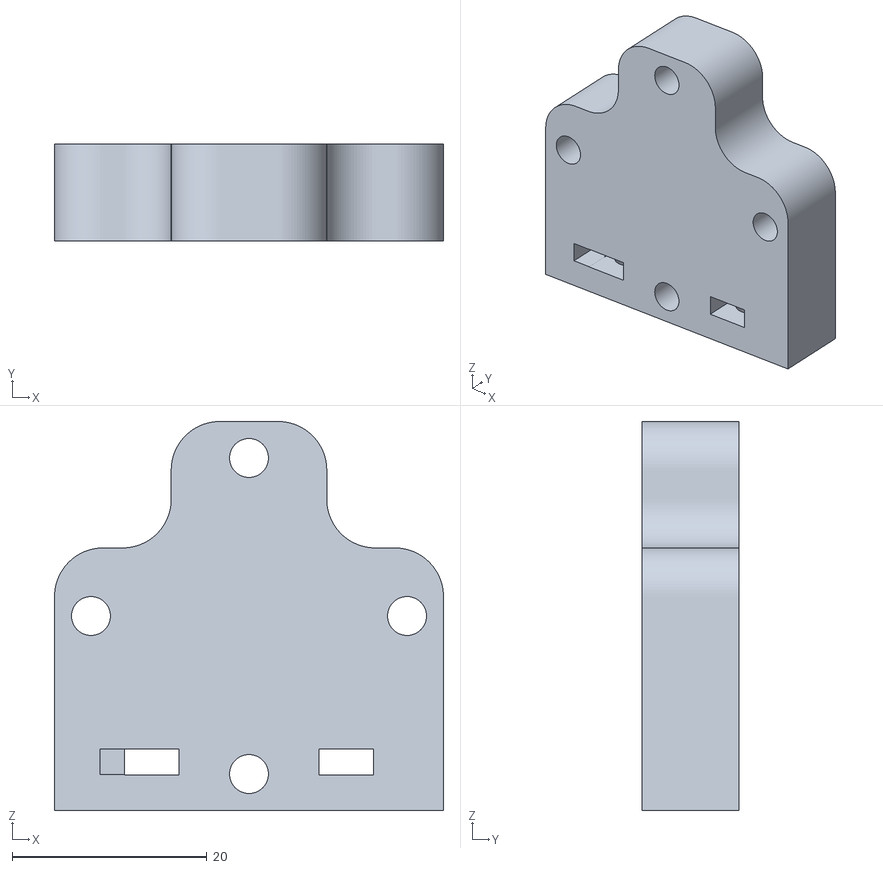
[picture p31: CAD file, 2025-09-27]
models/3D_Models/Motor Mouting Bracket.stl
40.0 x 10.0 x 40.0

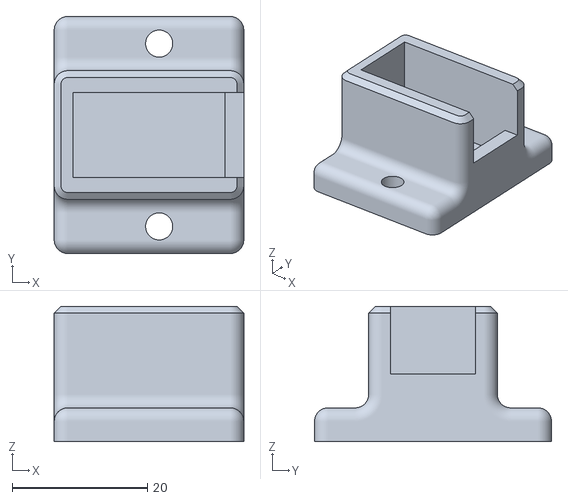
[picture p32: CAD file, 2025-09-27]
models/3D_Models/Servo holder.stl
28.0 x 35.0 x 20.0

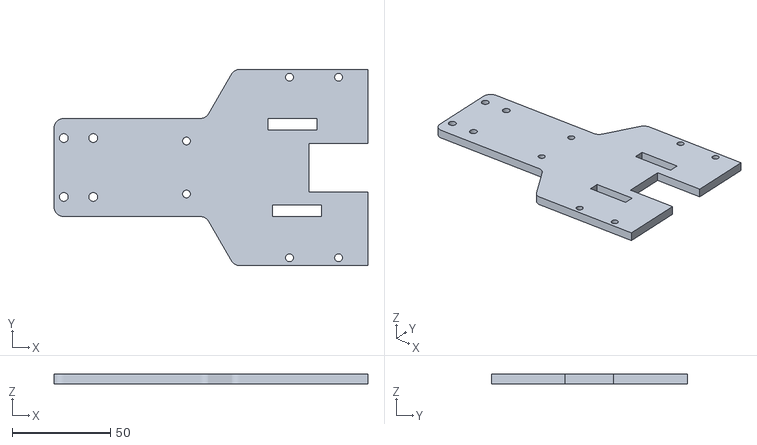
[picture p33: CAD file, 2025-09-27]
models/3D_Models/Upper Chassis.stl
160.0 x 100.0 x 5.00

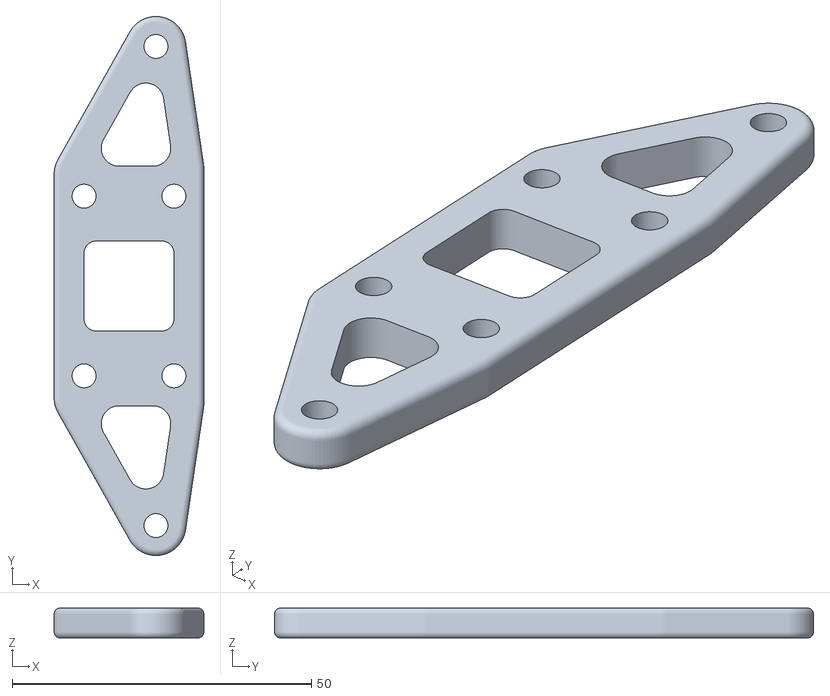
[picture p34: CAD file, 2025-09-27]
models/3D_Models/Front Arm.stl
25.0 x 90.0 x 5.00

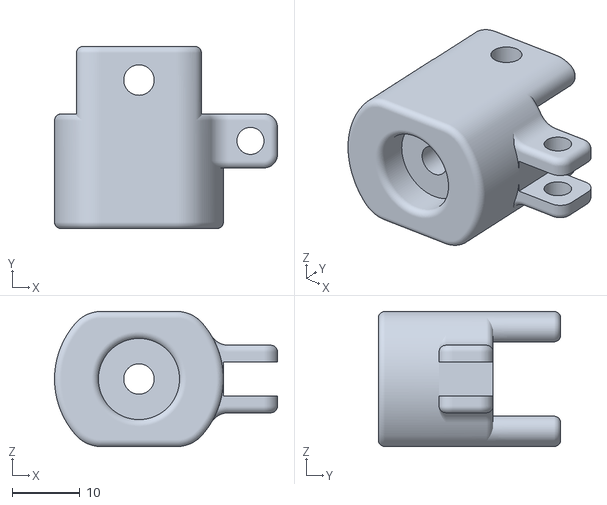
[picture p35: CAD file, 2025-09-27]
models/3D_Models/Front Axle right.stl
33.0 x 27.0 x 20.0

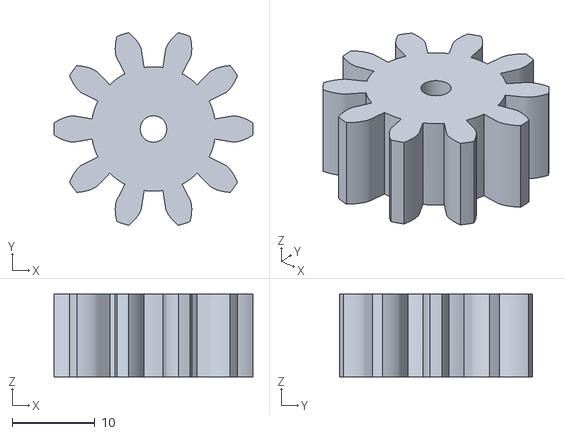
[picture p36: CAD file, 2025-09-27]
models/3D_Models/Gear 10 teeth v1.stl
24.0 x 23.2 x 10.0

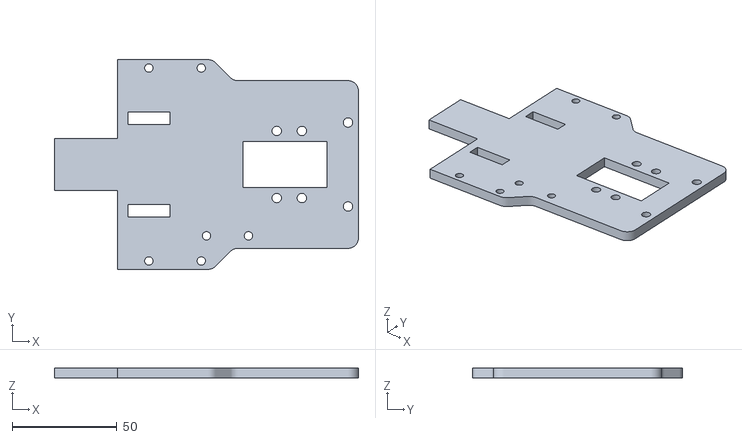
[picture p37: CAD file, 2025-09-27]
models/3D_Models/Rear Chassis v6.stl
145.0 x 100.0 x 5.00

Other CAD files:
models/3D_Models/Cover 2.stl
models/3D_Models/Front Axle left.stl

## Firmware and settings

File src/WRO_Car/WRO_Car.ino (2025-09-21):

/*
Code Descreption: 
Main WRO_Car code (Adafruit MPU6050 version)

Code_Purpose:
The main one, what do you think it's purpose (:, do fries ?? ofc move the car

Game Mat Size:
🧩 Game Mat Size: 3000 mm × 3000 mm
wroindia.org

📏 Allowed Tolerance: ± 5 mm in each direction

⬆️ Table Height/Borders: Built with 50 mm high borders to contain the mat 

CAR: 
30x20x30

Interior Square:
In Open Challenge rounds:
Corridor width can be either 600 mm (narrow) or 1000 mm (wide), ±100 mm tolerance 

In Obstacle Challenge rounds:
Corridor width is fixed at 1000 mm, ±10 mm tolerance 
where parking lot and ovsacles are placed

parking lot: 
width - 20 cm fixed, Length: 1.5 *  length of the robot
The parking lot is limited by two wood elements with 20 cm x 2 cm x 10 cm in magenta
The car might start from the starting lot (extra points) or in the middle zone
The colour of the parking lot limitation is magenta / RGB (255, 0, 255).

Traffic Sign:
width: 50 mm
The colour of the red traffic signs is RGB (238, 39, 55).
The colour of the green traffic signs is RGB (68, 214, 44)
Every parking lot limitation is a rectangular parallelepiped with dimensions 200x20x100
mm.
The diameter of the circle is 85 mm.



*/

/*
▶️ Red = Pass from the left side.
▶️ Green = Pass from the right side.
*/

#include "camera_detect.h"
#include "ultrasonic.h"
#include "imu.h"
#include "servo_motor.h"

#define GREEN_OBJECT 'G'
#define RED_OBJECT 'R'
#define NONE_OBJECT 'N'

#define LEFT_OBJECT 'L'
#define RIGHT_OBJECT 'R'
#define CENTER_OBJECT 'C'

// ======== IMU ========
sensors_event_t a, g, temp;
float turn_angle = 0;
unsigned long last_time = 0;
#include <Adafruit_MPU6050.h>
#include <Adafruit_Sensor.h>

Adafruit_MPU6050 imu;
// ======== IMU ========

const int MAX_DISTANCE_FROM_WALL_FORWARD = 95;
const int MAX_DISTANCE_FROM_WALL_LEFT = 60;
const int MAX_DISTANCE_FROM_WALL_RIGHT = 60;
const int MIN_DISTANCE_FROM_WALL_LEFT = 30;
const int MIN_DISTANCE_FROM_WALL_RIGHT = 30;
const int MAX_DISTANCE_FROM_OBJECT = 20;

const int IMU_MAX_DIFFERENCE = 5;

const int MAX_DISTANCE_TO_BACK = 0;

int angle1 = 0;
int angle2 = 90;
int base_angle = 45; // 70

void setup() {
  motor_setup();
  // ultrasonic_setup();
  // IMU_setup(imu);
  servo_setup();
  // set_servo_angle;'l''kkoooooooolpo(base_angle);
  

  Serial.begin(9600);
  Serial.println("Enter a servo angle (0 - 180):");

}

/*
Outputs:
Servo Motor: Go angle
Motor: Move
*/



/*
R/G/N
area (NUMBER OF PXELS)
direction (L/R/C)
difference

IMU: 
Z



Inputs:
Camera: color, area, direction, difference    
IMU: tunr_angle
Ultrasonic: rd, ld, fd
Motor_encoder: distance moved
*/ 


int current_angle = base_angle;
void loop() {
  // if (Serial.available() > 0)
  // {
  //   int angle = Serial.parseInt();
  //   move_for_angle(old_angle, angle);
  //   old_angle = angle;

  //   while (Serial.available() > 0) {
  //     Serial.read();
  //   }
    
  //   Serial.println("Enter next angle:");

  // }



  delay(4000);
  move_for_angle(&current_angle, 90, 220); // right 
  // set_servo_angle(0);
  delay(1500);
  move_for_angle(&current_angle, 0, 220); // right 
  // set_servo_angle(90);
  delay(1500);
  move_for_angle(&current_angle, 60, 255); // right 


  // set_speed(255);
  
  // move_for_angle(85, 0); // left
  // delay(1200);
  // move_for_angle(0, 60); // right
  // delay(500); 


  
  // move_for_angle(angle2, base_angle); // right
  // delay(1000);

  // set_servo_angle(70);
  // delay(1500);
  // set_servo_angle(20);
  // delay(1500);


  // move_for_angle(base_angle, angle1);
  // delay(2500);
  // move_for_angle(angle1, base_angle);
  // delay(5000);


  // // ============================== Camera Inputs ==============================
  // String object = get_object();
  // int firstColon = object.indexOf(':');
  // int secondColon = object.indexOf(':', firstColon + 1);
  // int thirdColon = object.indexOf(':', secondColon + 1);

  // char object_color = object.charAt(0); // R/G/N
  // int object_area = object.substring(firstColon + 1, secondColon).toInt(); // Number of pixels
  // char object_direction = object.charAt(secondColon + 1); // L/R/C
  // int object_difference = object.substring(thirdColon + 1).toInt(); // Differenec from center 
  // // ============================== Camera Inputs ==============================

  // // ============================== IMU Inputs ==============================
  // imu.getEvent(&a, &g, &temp);
  // unsigned long now = millis();
  // float dt = (now - last_time) / 1000.0;  // convert ms to seconds
  // last_time = now;

  // float gyro_z = g.gyro.z * 57.2958; // rad/s to °/s
  // turn_angle += gyro_z * dt;

  // Serial.println(turn_angle);
  // delay(10);

  // All IMU inputs
  // float imu_ax = a.acceleration.x / 9.81; // in g
  // float imu_ay = a.acceleration.y / 9.81;
  // float imu_az = a.acceleration.z / 9.81;

  // float imu_gx = g.gyro.x * 57.2958; // convert rad/s to °deg/s 
  // float imu_gy = g.gyro.y * 57.2958;
  // float imu_gz = g.gyro.z * 57.2958;
  // // ============================== IMU Inputs ==============================

  // // ============================== Ultrasonic Inputs ==============================
  // /*
  //   #define LEFT_US 2
  //   #define RIGHT_US 0
    // #define FRONT_US 1
  // */

  // float rd_ultrasonic = get_ultrasonic_output(trig_pins[RIGHT_US], echo_pins[RIGHT_US]);
  // float ld_ultrasonic = get_ultrasonic_output(trig_pins[LEFT_US], echo_pins[LEFT_US]);
  // float fd_ultrasonic = get_ultrasonic_output(trig_pins[FRONT_US], echo_pins[FRONT_US]);
  // Serial.println(fd_ultrasonic);
  // // ============================== Ultrasonic Inputs ==============================

  // // ============================== Motor Inputs ==============================
  // float total_distance = get_distance();
  // // ============================== Motor Inputs ==============================

  // print_inputs(object_color, object_area, object_direction, object_difference, turn_angle, rd_ultrasonic, ld_ultrasonic, fd_ultrasonic, total_distance);
  
  // delay(1000);
}

/*
#define GREEN_OBJECT 'G'
#define RED_OBJECT 'R'
#define NONE_OBJECT 'N'

#define LEFT_OBJECT 'L'
#define RIGHT_OBJECT 'R'
#define CENTER_OBJECT 'C'
*/

//                   object color  number of pixels     Left/Right/Center  how far from center    imu dimantions--------------------------------------------------------  ultrasonics data --------------------------------------------  total moved distance 
// void get_inputs(char object_color, int object_area, char object_direction, int object_difference, float turn_angle, float rd_ultrasonic, float ld_ultrasonic, float fd_ultrasonic, float total_distance)
// {

//   // ====================================================================================================
//   // if there's an obstacle front you
//   if (object_color != NONE_OBJECT)
//   {
//     // if the object GREEN
//     if (object_color == GREEN_OBJECT)
//     {
//       if (object_direction == RIGHT_OBJECT)
//       {
//         // MOVE FORWARD
//         move_forward();
//         return_center();
//         // Function for checking if there's hazarad
//       }

//       else if (object_direction == LEFT_OBJECT || object_direction == CENTER_OBJECT)
//       {
//         // Will see the ultra sonic output (if i can turn)
//         // if can't turn, MOVE BackWard **************************************************** (if no time to turn)
//         if (fd_ultrasonic <= MAX_DISTANCE_FROM_OBJECT)
//         {
//           move_back();
//           delay(1 * 1000); // one second
//         }

//         // if can turn 
//         // will turn according to the 1- C/R, 2- difference 
//         else
//         {
//           move_forward();
//           turn_left();
//           if (turn_angle != -90) // if IMU feed back is not good
//           {
//             set_servo_angle(150);
//           }
//         }

//         // after turning, keep traking the IMU
//         // Function for checking if there's hazarad
//       }
//     }

//     // if the object RED
//     else
//     {
//       if (object_direction == RIGHT_OBJECT)
//       {
//         // MOVE FORWARD
//         // Function for checking if there's hazarad
//         move_forward();
//         return_center();
//       }

//       else if (object_direction == LEFT_OBJECT || object_direction == CENTER_OBJECT)
//       {
//         if (fd_ultrasonic <= MAX_DISTANCE_FROM_OBJECT)
//         {
//           move_back();
//         }

//         else
//         {
//           move_forward();
//           turn_left();
//           if (turn_angle != 90)
//           {
//             set_servo_angle(35);
//           }
//         }

//         // Will see the ultra sonic output (if i can turn)
//         // if can't turn, MOVE BackWard
//         // if can turn 
//         // will turn according to the 1- C/L, 2- difference 
//         // after turning, keep traking the IMU
//         // Function for checking if there's hazarad
//       }
//     }
    
//   }
//   // ====================================================================================================
  
//   // If there's no obstacels
//   else
//   {
//     move_forward();
//     // MOVE FORWARD
//     // Function for checking if there's hazarad

//     // if it's time to turn
//     if (fd_ultrasonic <= MAX_DISTANCE_FROM_WALL_FORWARD)
//     {
//       // Then it's ok to turn left
//       if (ld_ultrasonic > MAX_DISTANCE_FROM_WALL_LEFT)
//       {
        
//         if (turn_angle != 90)
//         {
//           set_servo_angle(35);
//         }

//         else
//         {
//           turn_left();
//         }
//         // turn the servo 90 degree (left)
//         // IMU Detect
//       }

//       // Then it's ok to turn right
//       else if (rd_ultrasonic > MAX_DISTANCE_FROM_WALL_RIGHT)
//       {

//         if (turn_angle != 90)
//         {
//           set_servo_angle(150);
//         }

//         else
//         {
//           turn_right();
//         }
//         // turn the servo -90 degree (RIGHT)
//         // IMU Detect
//       }
//     }
//   }

// }

/*
Inputs:
Camera: color, area, direction, difference
IMU: ax, ay, az, gx, gy, gz
Ultrasonic: rd, ld, fd
Motor_encoder: distance moved
*/ 

void print_inputs(char object_color, int object_area, char object_direction, int object_difference, float turn_angle, float rd_ultrasonic, float ld_ultrasonic, float fd_ultrasonic, float total_distance)
{
  Serial.print("Turn_Aangle: ");
  Serial.print(turn_angle);

  Serial.print("Ultrasonic: R: ");
  Serial.print(rd_ultrasonic);
  Serial.print(" F: ");
  Serial.print(fd_ultrasonic);
  Serial.print(" L: ");
  Serial.println(ld_ultrasonic);

  Serial.print("Toal Distance");
  Serial.println(total_distance);
  Serial.println();
  Serial.println("=====================================");
  Serial.println();
}

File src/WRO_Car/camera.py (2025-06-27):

"""

Code Descreption: 
the main code (and the only) for the raspberry PI camera using python

Code_Purpose:
to detect red and green obstecales in the track then send serial data to the arduino according
to the observations

Libraries:
open_CV: to detect colors and extract shapes
serial: to comminicate with the arduino
picamera2: to get the data from the PI camera (module v3)
numpy: efficient way to deal with arrays
time: to do delays when needed


"""


import cv2
import numpy as np
from picamera2 import Picamera2
import time
import serial

# start serial communication
ser = serial.Serial('/dev/ttyUSB0', 9600, timeout=1)

# get the camera
picam2 = Picamera2()

# Set the window size, make BGR format
video_config = picam2.create_video_configuration(
    main={"size": (640, 480), "format": "BGR888"}
)
# imply the configurations
picam2.configure(video_config)

picam2.start()  # start the camera
time.sleep(1)   # give the camera time to warm up

# will create a 5X5 array of 1's, which is the minimum required to consider as shape
kernel = np.ones((5, 5), np.uint8)

print("Press 'q' to quit.")

# detect and return image + mask + color
def detect_colors():
    frame_pil = picam2.capture_image("main")  # capture the photo
    frame = np.array(frame_pil.convert("RGB"))  # convert the photo to RGB formate
    frame = cv2.cvtColor(frame, cv2.COLOR_RGB2BGR)  # Convert from RGB to OpenCV format (BGR)

    # Convert to HSV format
    hsv = cv2.cvtColor(frame, cv2.COLOR_BGR2HSV)

    # HSV range for red
    lower_red1 = np.array([0, 100, 100])
    upper_red1 = np.array([10, 255, 255])
    lower_red2 = np.array([160, 100, 100])
    upper_red2 = np.array([179, 255, 255])

    # HSV range for green
    lower_green = np.array([40, 70, 70])
    upper_green = np.array([85, 255, 255])

    # Masks for green and red (consider red/green white - other bits as black)
    mask1 = cv2.inRange(hsv, lower_red1, upper_red1)
    mask2 = cv2.inRange(hsv, lower_red2, upper_red2)
    red_mask = cv2.bitwise_or(mask1, mask2)
    green_mask = cv2.inRange(hsv, lower_green, upper_green)

    # ignore the shapes that are not in 5x5 range
    red_mask = cv2.morphologyEx(red_mask, cv2.MORPH_OPEN, kernel)
    green_mask = cv2.morphologyEx(green_mask, cv2.MORPH_OPEN, kernel)

    # find contours and use shape + area to detect valid objects
    def detect_color_from_mask(mask):
        # extracts the edges of white blobs in the mask.
        # RETR_EXTERNAL: only detects outermost contours (ignores holes inside shapes).
        # CHAIN_APPROX_SIMPLE: compresses points to reduce memory usage.
        contours, _ = cv2.findContours(mask, cv2.RETR_EXTERNAL, cv2.CHAIN_APPROX_SIMPLE)
        for cnt in contours:
            # Calculates the area in pixels of the shape. Small areas are usually noise or far objects.
            area = cv2.contourArea(cnt)
            if area < 2000:  # filter out small noise
                continue

            # detect a polygon shape
            approx = cv2.approxPolyDP(cnt, 0.04 * cv2.arcLength(cnt, True), True)
            if len(approx) >= 4:  # square or blob-like
                x, y, w, h = cv2.boundingRect(cnt)
                aspect_ratio = w / float(h)
                if 0.6 < aspect_ratio < 1.4:  # roughly square/rectangle
                    return True
        return False

    if detect_color_from_mask(red_mask):
        return frame, red_mask, green_mask, "RED"
    elif detect_color_from_mask(green_mask):
        return frame, red_mask, green_mask, "GREEN"

    return frame, red_mask, green_mask, "NONE"


def main():
    green_flag, red_flag, none_flag = False, False, False

    while True:
        # detect colors and return masks for display
        frame, red_mask, green_mask, data = detect_colors()

        # pop up a window to show the masks
        cv2.imshow("Camera View", frame)
        cv2.imshow("Red Mask", red_mask)
        cv2.imshow("Green Mask", green_mask)

        # when 'q', exit
        if cv2.waitKey(1) & 0xFF == ord('q'):
            break

        if data == "GREEN":
            if green_flag:
                continue
            ser.write(b'G')
            green_flag = True
            none_flag, red_flag = False, False
            print("GREEN")

        elif data == "RED":
            if red_flag:
                continue
            ser.write(b'R')
            red_flag = True
            green_flag, none_flag = False, False
            print("RED")

        else:
            if none_flag:
                continue
            ser.write(b'N')
            none_flag = True
            green_flag, red_flag = False, False
            print("None")


if __name__ == '__main__':
    try:
        main()
    finally:
        # clean after finish
        ser.close()
        cv2.destroyAllWindows()

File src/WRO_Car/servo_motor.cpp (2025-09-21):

/*
Code Descreption: 
part of WRO_car code for arduino, Specifically for Servo motor and Stering control

Code_Purpose:
decide to move the stering (srvo motor) left or right or keep still based on camera, IMU and other inputs

*/

#include "./servo_motor.h"
Servo steeringServo;

void servo_setup()
{
  steeringServo.attach(SERVO_PIN); // pin 12
  steeringServo.write(CENTER_ANGLE); // start from the center
  Serial.println("Enter a servo angle (0 - 180):");

}

void set_servo_angle(int angle)
{
  steeringServo.write(angle); // write the given angle to the servo motor
}

void move_for_angle(int *angle, int next_angle, int speed)
{
  int current_angle = *angle;
  set_speed(speed);
  delay(TURNINNG_DELAY);

  if (current_angle < next_angle)
  {
    for (int i = current_angle; i <= next_angle; i++)
    {
      set_servo_angle(i);
      delay(SERVO_DELAY);
    }
  }

  else if (current_angle > next_angle)
  {
    for (int i = current_angle; i >= next_angle; i--)
    {
      set_servo_angle(i);
      delay(SERVO_DELAY);
    }
  }

  *angle = next_angle;

}

void turn_right()
{
  steeringServo.write(RIGHT_ANGLE);
}


void turn_left()
{
  steeringServo.write(LEFT_ANGLE);
}

void return_center()
{
  steeringServo.write(CENTER_ANGLE);
}

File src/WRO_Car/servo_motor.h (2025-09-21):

/*
Code Descreption: 
part of WRO_car code for arduino, Specifically for Servo motor and Stering control

Code_Purpose:
decide to move the stering (srvo motor) left or right or keep still based on camera, IMU and other inputs

*/

#ifndef servo_motor_h
#define servo_motor_h

#include <Wire.h>
#include <Arduino.h>
#include <Servo.h>
#include "moving.h"

const int SERVO_PIN = 12;
const int CENTER_ANGLE = 45;
const int LEFT_ANGLE = 45;
const int RIGHT_ANGLE = 135;

#define SERVO_DELAY 14
#define TURNINNG_DELAY 600

void servo_setup();
void set_servo_angle(int);
void turn_left();
void turn_right();
void return_center();
void move_for_angle(int *, int, int);

#endif

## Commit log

2025-06-27 First commit, code proto type, Car schemetic, and repo structure
    [Car_Schematic.fzz]
2025-07-15 change the animation for steering
2025-07-15 Rename Servo Motor.jpg to Servo_Motor.jpg
2025-09-17 organize the wires, add the nre Sevro
    [Car_Schematic.fzz]
2025-09-17 add the new wirings
2025-09-21 edit some servo codes
2025-09-27 3d models edits
    [Arm Support.stl, Cover 2.stl, Cover.stl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]
